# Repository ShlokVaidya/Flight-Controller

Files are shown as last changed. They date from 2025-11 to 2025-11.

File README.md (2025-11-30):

# Single Flight Controller (SFC) – Project Documentation

This repository contains the design files, schematic, and explanation for my custom Single Flight Controller (SFC). The goal of this project was to create a compact, modular, and fully functional flight controller with built-in sensors, logging capability, and support for standard RC aircraft peripherals. This design was heavily inspired by Hack Club’s Guided Project: SFC.

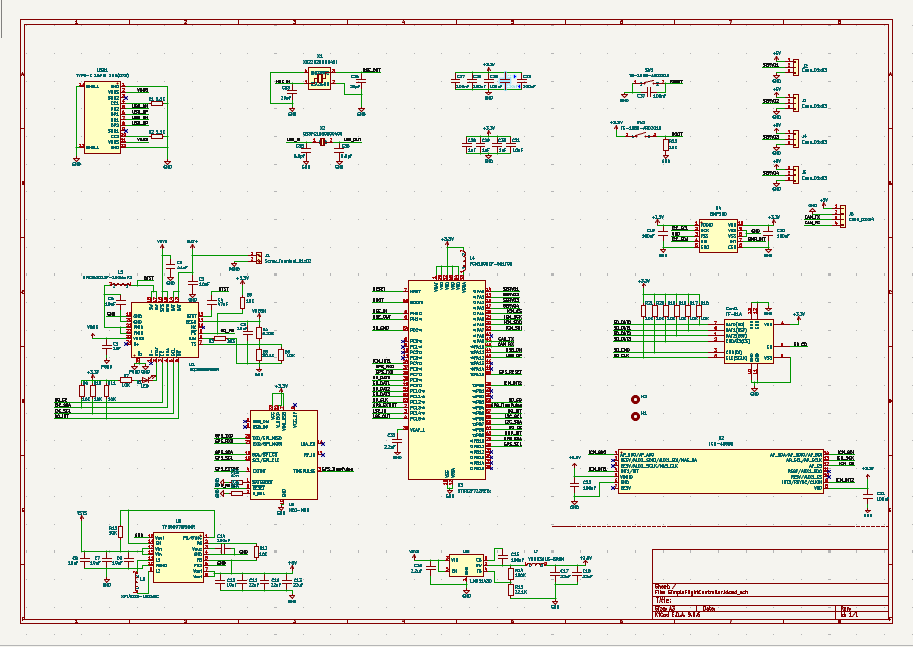
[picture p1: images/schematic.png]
Schematic


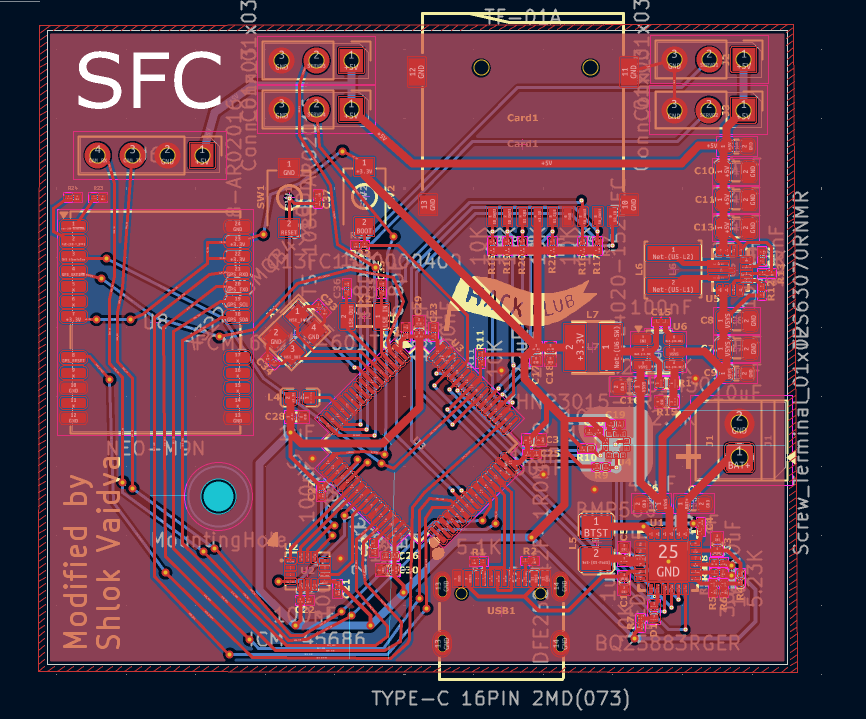
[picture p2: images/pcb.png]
PCB


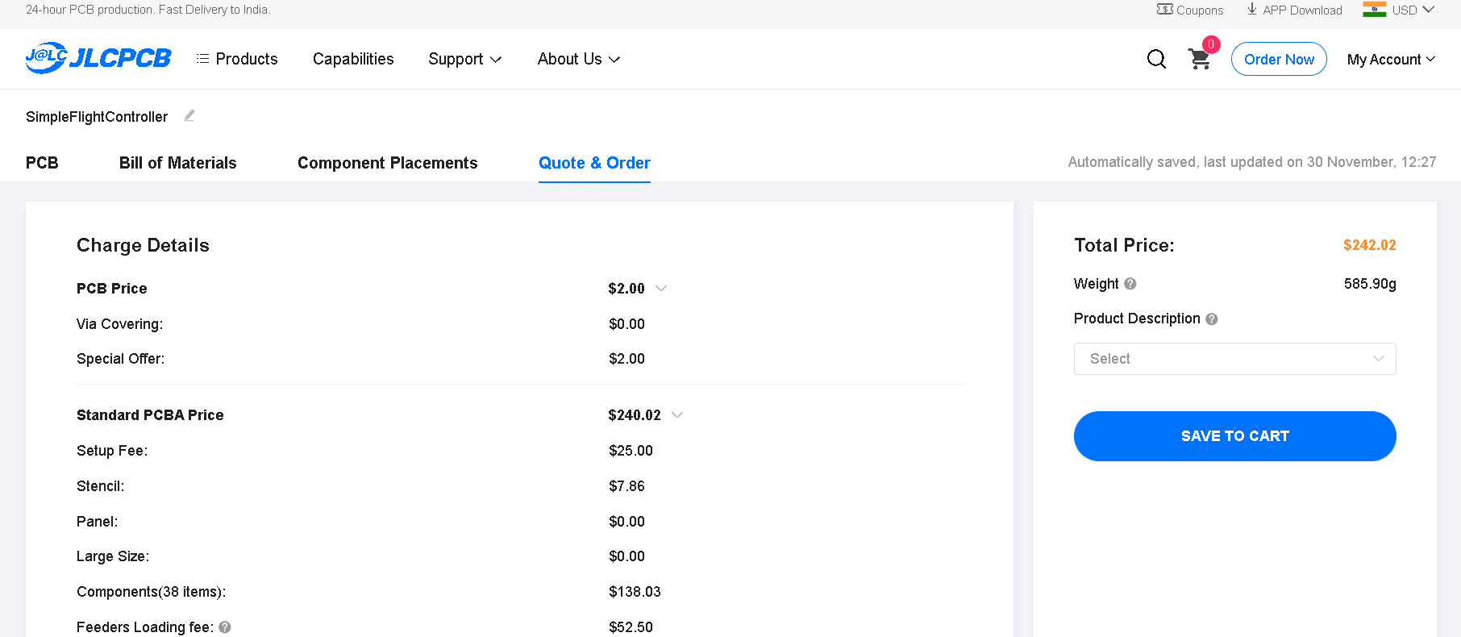
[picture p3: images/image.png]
Bill


## Overview

This flight controller integrates all the essential modules required for basic autonomous flight experimentation on a single PCB. It includes computation, sensing, logging, and connectivity features normally spread across multiple boards.

The system is built around an STM32 microcontroller, with supporting components for power regulation, sensor interfacing, GPS reception, and servo control.

---

## Features

### 1. Microcontroller

The design centers around an STM32F722RETx MCU. It provides high-speed processing, multiple UART/SPI/I2C peripherals, and enough GPIO pins for sensors and servo output.

### 2. Four 3-Pin Servo Connectors

The board includes four standard 3-pin (Signal, 5V, GND) servo output connectors.
These can be used for:

* Control surfaces (aileron, elevator, rudder)
* Throttle signal
* Or any PWM-output peripheral

The PCB includes appropriate decoupling capacitors and routing to ensure clean, low-noise PWM signals.

### 3. UART Port

A dedicated UART port is broken out on the PCB.
This can be used for:

* Telemetry modules
* Debug serial output
* External communication
* RC Receiver (if using SBUS or another serial protocol)

### 4. Built-In Sensors and Modules

#### GPS Module: u-blox Neo-M9N

A high-performance GNSS receiver is integrated directly onto the PCB.
Features include:

* Fast acquisition
* High update rate options
* Reliable lock in outdoor flight conditions
* Direct UART communication with the STM32

#### Barometer

The barometer module (BMP-series) provides altitude estimation for stability and navigation algorithms.
It interfaces over I2C and includes proper filtering capacitors for noise reduction.

#### Accelerometer and Temperature Sensor

An onboard IMU provides acceleration data for movement detection and flight stabilization.
Temperature reading is also used internally by IMUs to compensate sensor drift.

### 5. SD Card Slot for Data Logging

The board includes a microSD card slot for logging flight data such as:

* GPS coordinates
* Barometric altitude
* Acceleration
* Temperature
* System debug information

The microcontroller communicates with the SD card via SPI.

### 6. Power Management

The design includes onboard regulators and filtering stages to provide stable supplies for:

* 5V rail (servos and peripherals)
* 3.3V rail (MCU, sensors, GPS)
* Noise isolation between digital and analog sections

---

## How the Flight Controller Was Designed

### Schematic Stage

I began by identifying the essential modules needed for the first version of the flight controller. I collected reference designs from datasheets and existing open-source boards, then arranged everything into a master schematic. Each module was divided into blocks:

* MCU core section
* Power regulation
* Servo outputs
* GPS
* Sensors (Barometer + IMU)
* SD card interface
* UART and additional connectors

I ensured all power, ground, and communication lines were properly labeled and referenced across schematic pages.

### PCB Routing

This was the most challenging part of the entire project.

#### Challenges Faced

1. **Dense routing around the STM32F7 MCU**
   The microcontroller has many high-speed pins in tight clusters. Routing SPI, I2C, UART, SWD, and PWM signals without crossing too many traces was difficult.

2. **Interference concerns between GPS and digital signals**
   GPS modules are sensitive to noise. Keeping the antenna section clean required careful placement and ground-plane management.

3. **Power distribution**
   Servos can draw significant current. Ensuring thick enough traces and minimizing voltage drops was a challenge.

4. **SD Card signal integrity**
   SPI lines need clean routing and matched lengths to avoid read/write instability. I had to reroute multiple times to avoid crosstalk.

5. **Fitting everything on a reasonable board size**
   With multiple connectors, sensors, and the MCU, arranging components efficiently took several iterations.

### What I Learned

1. **Importance of reference designs**
   Studying vendor schematics helped avoid basic mistakes, especially with decoupling and pull-up requirements.

2. **Routing strategy matters**
   Planning major traces (power rails, GPS lines, SD card lines) before others saves time.

3. **Decoupling capacitors are not optional**
   Correct placement greatly affected reliability during testing.

4. **Grounding techniques for mixed-signal boards**
   Separating analog and digital grounds and using ground pours improved noise performance.

5. **Iterative design is normal**
   The first layout is rarely perfect. Revision cycles teach you more than documentation ever will.

---

## Reference

This project was inspired by and based on concepts from Hack Club’s Guided Project: Single Flight Controller (SFC).

Their documentation, examples, and approach helped me understand:

* How to break complex designs into modular blocks
* Good PCB routing practices
* How sensing modules interact on a flight controller
* The importance of logging and debugging tools

---

## Conclusion

This Single Flight Controller is the result of combining research, reference designs, and hands-on PCB design practice. With integrated GPS, IMU, barometer, servo outputs, UART, and SD card logging on one board, it serves as a compact platform for experimenting with flight algorithms and embedded systems.

Note: 
Due to unavaiable components on JLCPCB i would request to get tickets instead of the PCB.

Thank You,
Shlok Vaidya

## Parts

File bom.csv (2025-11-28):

Item | Price | Source
PCB | 190 | JLCPCB

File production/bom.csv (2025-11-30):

Designator | Footprint | Quantity | Value | LCSC Part #
C1, C28, C29, C30 | 0402 | 4 | 1uF
C10, C11, C13 | 0805 | 3 | 22uF
C12, C2, C9 | 0603 | 3 | 10uF
C14, C15, C19, C20, C21, C22, C23, C24, C25, C26, C27, C37 | 0201 | 12 | 100nF
C16 | 0603 | 1 | 2.2uF
C17, C18 | 0402 | 2 | 22uF
C3, C31, C5 | 0402 | 3 | 10uF
C32 | 0201 | 1 | 2.2uF
C33, C34 | 0201 | 2 | 20pF
C35, C36 | 0201 | 2 | 6.8pF
C4 | 0201 | 1 | 47nF
C6 | 0603 | 1 | 44uF
C7, C8 | 0805 | 2 | 10uF
CARD1 | TF-SMD_TF-01A | 1 | TF-01A | C91145
D1 | 0402 | 1 | LED
J1 | TerminalBlock_Xinya_XY308-2.54-2P_1x02_P2.54mm_Horizontal | 1 | Screw_Terminal_01x02
J2, J3, J4, J5 | PinHeader_1x03_P2.54mm_Vertical | 4 | Conn_01x03
J6 | PinHeader_1x04_P2.54mm_Vertical | 1 | Conn_01x04
L4 | L0603 | 1 | FCM1608KF-601T03 | C141723
L5 | L2520 | 1 | DFE252012F-1R0M=P2 | C435392
L6 | IND-SMD_L4.0-W4.0-A | 1 | XFL4020-152MEC | C3033018
L7 | IND-SMD_L3.0-W3.0 | 1 | YHNR3015-5R6M | C18236327
R1, R2 | 0201 | 2 | 5.1K
R10, R11, R12, R13, R16, R17, R18, R19, R20, R21, R22, R23, R24, R6, R7, R8, R9 | 0201 | 17 | 10K
R14 | 0402 | 1 | 100K
R15 | 0402 | 1 | 22.1K
R3 | 0201 | 1 | 383
R4 | 0201 | 1 | 5.23K
R5 | 0201 | 1 | 30.1K
SW1, SW2 | SW-SMD_L3.9-W3.0-P4.45 | 2 | TS-1088-AR02016 | C720477
U1 | VFQFPN-24_L4.0-W4.0-P0.50-BL-EP2.8 | 1 | BQ25883RGER | C544362
U2 | LGA-14_L3.0-W2.5-P0.50-TL | 1 | ICM-45686 | C22459454
U3 | LQFP-64_10x10mm_P0.5mm | 1 | STM32F722RETx
U4 | LGA-10_L2.0-W2.0-P0.50-TL_BMP580 | 1 | BMP580 | C22391138
U5 | VQFN-HR-15_L3.0-W2.5-P0.50-BL_TPS63070RNMR | 1 | TPS63070RNMR | C109322
U6 | SOT-23-6 | 1 | LMR51430
U8 | ublox_NEO | 1 | NEO-M9N
USB1 | USB-C-SMD_TYPE-C-6PIN-2MD-073 | 1 | TYPE-C 16PIN 2MD(073) | C2765186
X1 | CRYSTAL-SMD_4P-L3.2-W2.5-BL | 1 | X322525MOB4SI | C9006
X2 | FC-135R_L3.2-W1.5 | 1 | Q13FC1350000400 | C32346

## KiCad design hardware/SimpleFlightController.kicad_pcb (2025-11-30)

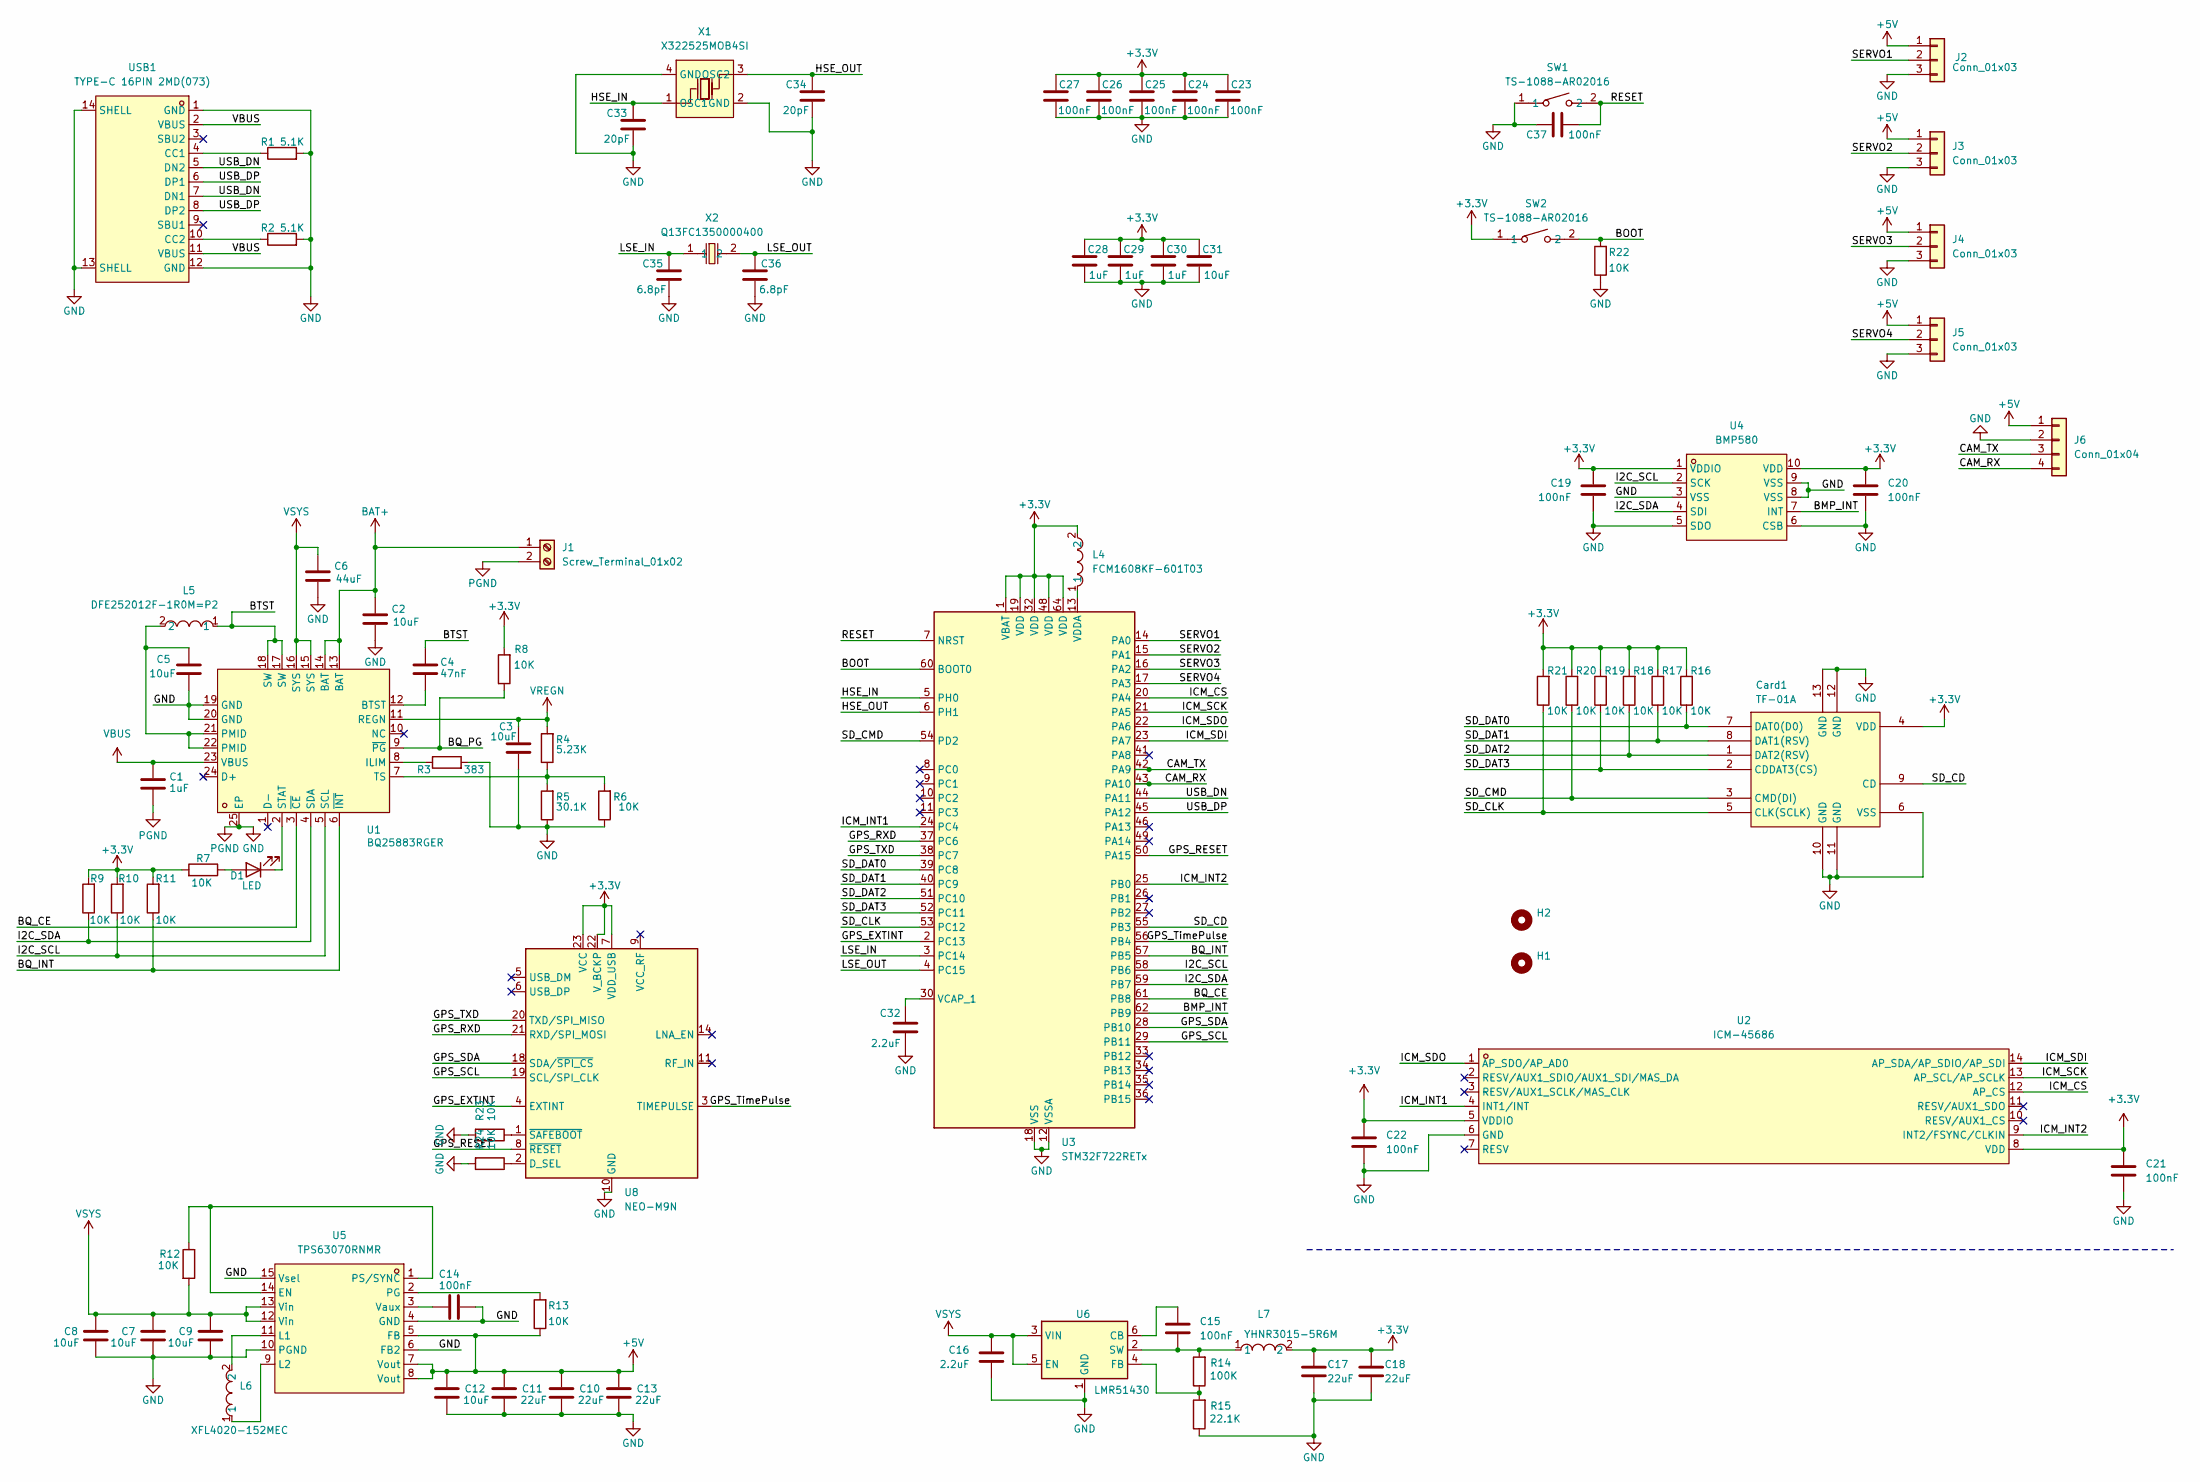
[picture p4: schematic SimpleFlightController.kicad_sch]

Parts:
C1, C28, C29, C30: 1uF; C_0402_1005Metric
C2, C9, C12: 10uF; C_0603_1608Metric
C3, C5, C31: 10uF; C_0402_1005Metric
C4: 47nF; C_0201_0603Metric
C6: 44uF; C_0603_1608Metric
C7, C8: 10uF; C_0805_2012Metric
C10, C11, C13: 22uF; C_0805_2012Metric
C14, C15, C19, C20, C21, C22, C23, C24, C25, C26, C27, C37: 100nF; C_0201_0603Metric
C16: 2.2uF; C_0603_1608Metric
C17, C18: 22uF; C_0402_1005Metric
C32: 2.2uF; C_0201_0603Metric
C33, C34: 20pF; C_0201_0603Metric
C35, C36: 6.8pF; C_0201_0603Metric
Card1: TF-01A; TF-SMD_TF-01A; LCSC Part C91145
D1: LED; LED_0402_1005Metric
H1, H2: MountingHole; MountingHole_2.2mm_M2
J1: Screw_Terminal_01x02; TerminalBlock_Xinya_XY308-2.54-2P_1x02_P2.54mm_Horizontal
J2, J3, J4, J5: Conn_01x03; PinHeader_1x03_P2.54mm_Vertical
J6: Conn_01x04; PinHeader_1x04_P2.54mm_Vertical
L4: FCM1608KF-601T03; L0603; LCSC Part C141723
L5: DFE252012F-1R0M=P2; L2520; LCSC Part C435392
L6: XFL4020-152MEC; IND-SMD_L4.0-W4.0-A; LCSC Part C3033018
L7: YHNR3015-5R6M; IND-SMD_L3.0-W3.0; LCSC Part C18236327
R1, R2: 5.1K; R_0201_0603Metric
R3: 383; R_0201_0603Metric
R4: 5.23K; R_0201_0603Metric
R5: 30.1K; R_0201_0603Metric
R6, R7, R8, R9, R10, R11, R12, R13, R16, R17, R18, R19, R20, R21, R22, R23, R24: 10K; R_0201_0603Metric
R14: 100K; R_0402_1005Metric
R15: 22.1K; R_0402_1005Metric
SW1, SW2: TS-1088-AR02016; SW-SMD_L3.9-W3.0-P4.45; LCSC Part C720477
U1: BQ25883RGER; VFQFPN-24_L4.0-W4.0-P0.50-BL-EP2.8; LCSC Part C544362
U2: ICM-45686; LGA-14_L3.0-W2.5-P0.50-TL; LCSC Part C22459454
U3: STM32F722RETx; LQFP-64_10x10mm_P0.5mm
U4: BMP580; LGA-10_L2.0-W2.0-P0.50-TL_BMP580; LCSC Part C22391138
U5: TPS63070RNMR; VQFN-HR-15_L3.0-W2.5-P0.50-BL_TPS63070RNMR; LCSC Part C109322
U6: LMR51430; SOT-23-6
U8: NEO-M9N; ublox_NEO
USB1: TYPE-C 16PIN 2MD(073); USB-C-SMD_TYPE-C-6PIN-2MD-073; LCSC Part C2765186
X1: X322525MOB4SI; CRYSTAL-SMD_4P-L3.2-W2.5-BL; LCSC Part C9006
X2: Q13FC1350000400; FC-135R_L3.2-W1.5; LCSC Part C32346

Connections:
+3.3V: C17.1, C18.1, C19.1, C20.1, C21.1, C22.1, C23.1, C24.1, C25.1, C26.1, C27.1, C28.1, C29.1, C30.1, C31.1, Card1.4 (VDD), L4.2, L7.2, R7.2, R8.2, R9.2, R10.2, R11.2, R16.2, R17.2, R18.2, R19.2, R20.2, R21.2, SW2.1, U2.5 (VDDIO), U2.8 (VDD), U3.1 (VBAT), U3.19 (VDD), U3.32 (VDD), U3.48 (VDD), U3.64 (VDD), U4.1 (VDDIO), U4.10 (VDD), U8.7 (VDD_USB), U8.22 (V_BCKP), U8.23 (VCC)
+5V: C10.1, C11.1, C12.1, C13.1, J2.1, J3.1, J4.1, J5.1, J6.1, R13.1, U5.5 (FB), U5.7 (Vout), U5.8 (Vout)
/BMP_INT: U3.62 (PB9), U4.7 (INT)
/BOOT: R22.2, SW2.2, U3.60 (BOOT0)
/BQ_CE: U1.3 (~CE), U3.61 (PB8)
/BQ_INT: R11.1, U1.6 (~INT), U3.57 (PB5)
/BQ_PG: R8.1, U1.9 (~PG)
/BTST: C4.1, L5.1, U1.17 (SW), U1.18 (SW)
/CAM_RX: J6.4, U3.43 (PA10)
/CAM_TX: J6.3, U3.42 (PA9)
/GPS_EXTINT: U3.2 (PC13), U8.4 (EXTINT)
/GPS_RESET: U3.50 (PA15), U8.8 (~RESET)
/GPS_RXD: U3.37 (PC6), U8.21 (RXD/SPI_MOSI)
/GPS_SCL: U3.29 (PB11), U8.19 (SCL/SPI_CLK)
/GPS_SDA: U3.28 (PB10), U8.18 (SDA/~SPI_CS)
/GPS_TXD: U3.38 (PC7), U8.20 (TXD/SPI_MISO)
/GPS_TimePulse: U3.56 (PB4), U8.3 (TIMEPULSE)
/HSE_IN: C33.1, U3.5 (PH0), X1.1 (OSC1)
/HSE_OUT: C34.1, U3.6 (PH1), X1.3 (OSC2)
/I2C_SCL: R10.1, U1.5 (SCL), U3.58 (PB6), U4.2 (SCK)
/I2C_SDA: R9.1, U1.4 (SDA), U3.59 (PB7), U4.4 (SDI)
/ICM_CS: U2.12 (AP_CS), U3.20 (PA4)
/ICM_INT1: U2.4 (INT1/INT), U3.24 (PC4)
/ICM_INT2: U2.9 (INT2/FSYNC/CLKIN), U3.25 (PB0)
/ICM_SCK: U2.13 (AP_SCL/AP_SCLK), U3.21 (PA5)
/ICM_SDI: U2.14 (AP_SDA/AP_SDIO/AP_SDI), U3.23 (PA7)
/ICM_SDO: U2.1 (AP_SDO/AP_AD0), U3.22 (PA6)
/LSE_IN: C35.1, U3.3 (PC14), X2.1
/LSE_OUT: C36.1, U3.4 (PC15), X2.2
/RESET: C37.2, SW1.2, U3.7 (NRST)
/SD_CD: Card1.9 (CD), U3.55 (PB3)
/SD_CLK: Card1.5 (CLK(SCLK)), R21.1, U3.53 (PC12)
/SD_CMD: Card1.3 (CMD(DI)), R20.1, U3.54 (PD2)
/SD_DAT0: Card1.7 (DAT0(D0)), R16.1, U3.39 (PC8)
/SD_DAT1: Card1.8 (DAT1(RSV)), R17.1, U3.40 (PC9)
/SD_DAT2: Card1.1 (DAT2(RSV)), R18.1, U3.51 (PC10)
/SD_DAT3: Card1.2 (CDDAT3(CS)), R19.1, U3.52 (PC11)
/SERVO1: J2.2, U3.14 (PA0)
/SERVO2: J3.2, U3.15 (PA1)
/SERVO3: J4.2, U3.16 (PA2)
/SERVO4: J5.2, U3.17 (PA3)
/USB_DN: U3.44 (PA11), USB1.5 (DN2), USB1.7 (DN1)
/USB_DP: U3.45 (PA12), USB1.6 (DP1), USB1.8 (DP2)
BAT+: C2.1, J1.1, U1.13 (BAT), U1.14 (BAT)
GND: C1.2, C2.2, C3.2, C5.2, C6.2, C7.2, C8.2, C9.2, C10.2, C11.2, C12.2, C13.2, C14.2, C16.2, C17.2, C18.2, C19.2, C20.2, C21.2, C22.2, C23.2, C24.2, C25.2, C26.2, C27.2, C28.2, C29.2, C30.2, C31.2, C32.2, C33.2, C34.2, C35.2, C36.2, C37.1, Card1.6 (VSS), Card1.10 (GND), Card1.11 (GND), Card1.12 (GND), Card1.13 (GND), J1.2, J2.3, J3.3, J4.3, J5.3, J6.2, R1.2, R2.2, R3.2, R5.1, R6.1, R15.1, R22.1, R23.2, R24.2, SW1.1, U1.19 (GND), U1.20 (GND), U1.25 (EP), U2.6 (GND), U3.12 (VSSA), U3.18 (VSS), U3.31 (VSS), U3.47 (VSS), U3.63 (VSS), U4.3 (VSS), U4.5 (SDO), U4.6 (CSB), U4.8 (VSS), U4.9 (VSS), U5.4 (GND), U5.6 (FB2), U5.10 (PGND), U5.15 (Vsel), U6.1 (GND), U8.10 (GND), U8.12 (GND), U8.13 (GND), U8.24 (GND), USB1.1 (GND), USB1.12 (GND), USB1.13 (SHELL), USB1.14 (SHELL), X1.2 (GND), X1.4 (GND)
unnamed: C5.1, L5.2, U1.21 (PMID), U1.22 (PMID)
unnamed: D1.2 (A), R7.1
unnamed: D1.1 (K), U1.2 (STAT)
unnamed: C4.2, U1.12 (BTST)
unnamed: R3.1, U1.8 (ILIM)
unnamed: R4.1, R5.2, R6.2, U1.7 (TS)
unnamed: C32.1, U3.30 (VCAP_1)
unnamed: L4.1, U3.13 (VDDA)
unnamed: R12.1, U5.1 (PS/SYNC), U5.14 (EN)
unnamed: L6.2, U5.11 (L1)
unnamed: L6.1, U5.9 (L2)
unnamed: R13.2, U5.2 (PG)
unnamed: C14.1, U5.3 (Vaux)
unnamed: C15.1, U6.6 (CB)
unnamed: R14.1, R15.2, U6.4 (FB)
unnamed: C15.2, L7.1, R14.2, U6.2 (SW)
unnamed: R24.1, U8.2 (D_SEL)
unnamed: R23.1, U8.1 (~SAFEBOOT)
unnamed: R1.1, USB1.4 (CC1)
unnamed: R2.1, USB1.10 (CC2)
VBUS: C1.1, U1.23 (VBUS), USB1.2 (VBUS), USB1.11 (VBUS)
VREGN: C3.1, R4.2, U1.11 (REGN)
VSYS: C6.1, C7.1, C8.1, C9.1, C16.1, R12.2, U1.15 (SYS), U1.16 (SYS), U5.12 (Vin), U5.13 (Vin), U6.3 (VIN), U6.5 (EN)

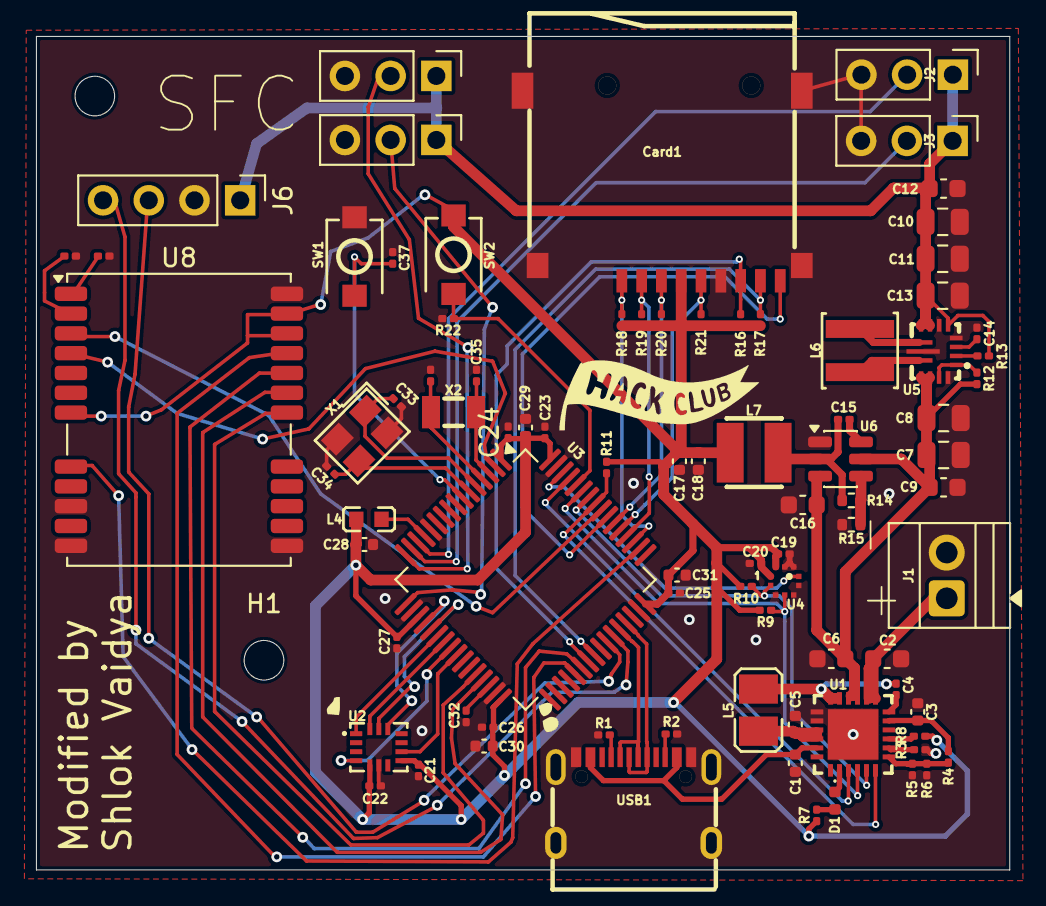
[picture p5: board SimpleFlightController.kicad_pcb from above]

Board: 2 copper layers, 54.1 x 46.3 mm, 87 parts (0 on the bottom side), 68 nets.

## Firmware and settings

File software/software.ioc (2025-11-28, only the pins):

Mcu.UserName=STM32F722RETx
PA0-WKUP.Signal=S_TIM2_CH1_ETR
PA1.Signal=S_TIM2_CH2
PA11.Signal=USB_OTG_FS_DM
PA12.Signal=USB_OTG_FS_DP
PA4.Signal=SPI1_NSS
PA5.Signal=SPI1_SCK
PA6.Signal=SPI1_MISO
PA7.Signal=SPI1_MOSI
PB0.GPIO_Label=ICM_INT2
PB0.Signal=GPXTI0
PB3.GPIO_Label=SD_CS
PB3.Signal=GPIO_Input
PB5.GPIO_Label=BQ_INT
PB5.Signal=GPXTI5
PB6.Signal=I2C1_SCL
PB7.Signal=I2C1_SDA
PB8.GPIO_Label=BQ_CE
PB8.Signal=GPIO_Output
PB9.GPIO_Label=BMP_INT
PB9.Signal=GPXTI9
PC10.Signal=SDMMC1_D2
PC11.Signal=SDMMC1_D3
PC12.Signal=SDMMC1_CK
PC14-OSC32_IN.Signal=RCC_OSC32_IN
PC15-OSC32_OUT.Signal=RCC_OSC32_OUT
PC4.GPIO_Label=ICM_INT1
PC4.Signal=GPXTI4
PC8.Signal=SDMMC1_D0
PC9.Signal=SDMMC1_D1
PD2.Signal=SDMMC1_CMD
PH0-OSC_IN.Signal=RCC_OSC_IN
PH1-OSC_OUT.Signal=RCC_OSC_OUT

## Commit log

2025-11-28 SFC v1.2
    [SimpleFlightController.csv, bom.csv, designators.csv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]
2025-11-30 SFC v2
    [SimpleFlightController.kicad_pcb, SimpleFlightController.kicad_sch, bom.csv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]
